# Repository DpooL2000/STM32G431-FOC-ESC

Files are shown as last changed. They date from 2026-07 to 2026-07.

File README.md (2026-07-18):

# Bare-Metal Sensorless FOC Kernel

This repository contains the hardware designs and bare-metal firmware kernels for a high-frequency sensorless FOC drive engine optimized for low-inductance UAV motors.

## System Architecture

*   **Microcontroller:** STM32G431 (170MHz Cortex-M4, utilizing internal CORDIC hardware co-processor).
*   **Target Dynamics:** 2300KV BLDC motor turning a 5-inch tri-blade propeller.
*   **Stator Identification Profile:**
    *   Phase Inductance (Ls): ~31 μH
    *   Phase Resistance (Rs): ~90 mΩ
    *   Flux Linkage (λ): ~0.00041 Wb
*   **Power Stage:** Discrete IR2101 gate drivers driving AOT418 MOSFETs, decoupled via high-speed 6N137 optocouplers for hardware shoot-through mitigation.
*   **Current Topology:** Injected low-side sensing through AD8418 current amplifiers paired with 2 mΩ shunts.

---

## Firmware Kernel Breakdown

### Core Execution Modules
*   **Pure Voltage Mode Engine:** Bypasses traditional high-lag PI current controllers to prevent phase delay at electrical frequencies exceeding 1500 Hz (30,000+ RPM).
*   **State-Space Flux Observer:** Zero-lag geometric flux estimation running at a rigid 24 kHz cycle using hardware CORDIC `get_Fast_Atan2()` calculations.
*   **Synchronous PWM Sampling:** Injected ADC conversions strictly aligned to center-count PWM timer events to read phase currents during low-side switching "quiet zones".

### The 5-Stage Spooling Sequence
1.  **OFF / CALIBRATE:** Measures operational amplifier baseline offsets.
2.  **ALIGN:** Asserts static vector to orient the rotor precisely at 0°.
3.  **OPEN_LOOP_RAMP:** Executes high-frequency blind step injection to break stator cogging torque.
4.  **FOC_BLEND:** Computes vector cross-fade from open-loop tracking to observer loop lock.
5.  **CLOSED_LOOP_FOC:** Complete handoff to pure sensorless geometric tracking.

---

## The High-RPM Non-Linear Boundary ("The Jerk")

A dedicated engineering post-mortem detailing why textbook industrial algorithms break down under microhenry, ultra-low mass environments:

*   **Cross-Coupling Destabilization:** At 40%–50% throttle, a microscopic 40 μs computational latency combined with intense reactive back-EMF cross-coupling (V = -ω * L * Iq) forces massive D-axis current (Id) spikes that derail the flux observer.
*   **Textbook Failures Documented:**
    *   **ADC Slew Limiting:** Clamping di/dt transitions starved the observer because a 31 μH coil at 12 V naturally generates an massive ~387,000 A/s rise rate.
    *   **Digital Flywheel PLLs:** Inertial filters introduced excessive mathematical phase lag, failing to track the sharp mechanical acceleration profiles of light drone props.

---

## Hardware Realities & Deadtime Distortion

*   **Pulse Devourment:** Insights on trying to execute an asymmetrical multirate loop (48 kHz PWM / 24 kHz FOC).
*   **The Math vs. Reality:** At 48 kHz, a 10% throttle command requires highly narrow 2.08 μs pulses. The gate driver's unavoidable physical deadtime (~0.5 μs) swallows a massive portion of the pulse width. This starves the stator coils of actual voltage relative to what the observer calculates, crashing the engine.
*   **Mitigation Strategy:** Reverted to a strictly synchronous 1:1 execution framework (24 kHz PWM / 24 kHz FOC) to preserve physical pulse widths.

---

## Live Telemetry Architecture

*   **The Binary Stream:** A raw, low-overhead 49-byte struct pushed at 1 kHz over a custom 2 Mbaud UART pipeline.
*   **UI Parser:** Custom PyQtGraph-driven GUI visualizing localized metrics (Id, Iq, Vd, Vq, and phase lag angle) in real-time.

---

## Repository Layout

*   **/hardware**: Layout files, optocoupler isolation circuits, and gate driver schematics.
*   **/firmware**: Clean bare-metal C modules, calibration tools, and parameter identification scripts.

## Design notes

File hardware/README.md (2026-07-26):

# Hardware Engineering & Power Stage Architecture

This directory contains the schematic and PCB layout for the bare-metal STM32G431 ESC, designed specifically for high-frequency sensorless FOC.

<p align="center">
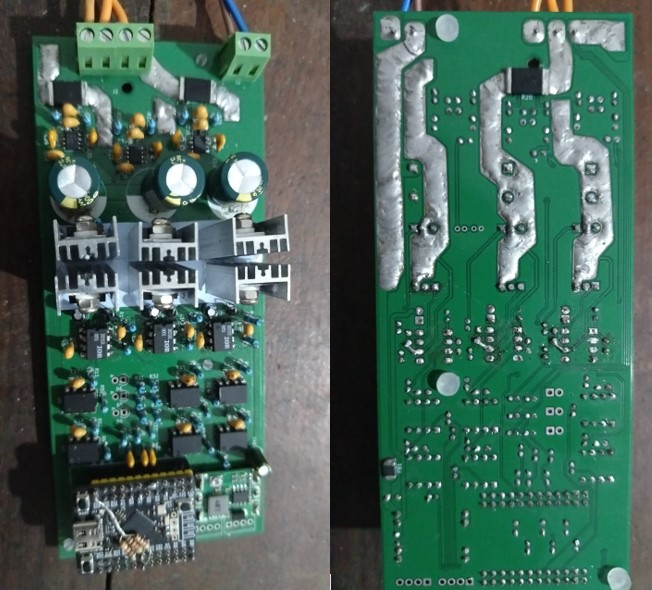
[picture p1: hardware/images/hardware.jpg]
Carrier Board Layout

</p>

## Power Stage & Isolation Topology
* **Gate Drivers:** Discrete IR2101 drivers pushing IRFZ44N MOSFETs.
* **Galvanic Isolation:** High-speed 6N137 optocouplers isolate the logic layer (STM32) from the power stage to prevent ground bounce and protect against high *di/dt* switching noise.
* **Power Management:** MP1584 Buck converter stepping the main 12V bus down to a stable 5V for logic and gate driver staging.

## Switching Dynamics & Thermal Constraints
The hardware was simulated and validated against exact MOSFET switching characteristics:
* **Miller Plateau Management:** Gate charge limits and switching losses were modeled at varying drive currents to optimize the transition through the Miller Plateau.
* **Shoot-Through Protection:** Hardware deadtime is physically characterized at 900 ns to ensure absolute safe-state switching during high/low side handoffs.

## Signal Conditioning & Analog Front End (AFE)
* **Current Sensing:** Low-side current measurement utilizing 2 mΩ shunts paired with AD8418 current sense amplifiers for precision synchronous sampling.
* **BEMF Sensing:** Phase voltages (A, B, C) are stepped down via precise resistor divider networks (10k/1k).
* **Hardware Filtering:** The BEMF signals pass through dedicated RC low-pass filters tuned to a 172.1 kHz cutoff frequency, resulting in a known, deterministic 7.9° phase lag that is compensated for in software.

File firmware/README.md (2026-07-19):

# Firmware Kernel & Control Systems

This directory contains the bare-metal C implementation of the sensorless FOC loop, executing on the STM32G431 Cortex-M4.

## Hardware Abstraction & Pin Mapping
The system is tightly coupled to the MCU hardware timers and ADCs for deterministic execution:

| Function | Signal | STM32 Pin | Peripheral / Channel |
| :--- | :--- | :--- | :--- |
| **Phase U PWM** | High / Low | PA8 / PB13 | TIM1_CH1 / TIM1_CH1N |
| **Phase V PWM** | High / Low | PA9 / PB14 | TIM1_CH2 / TIM1_CH2N |
| **Phase W PWM** | High / Low | PA10 / PB15 | TIM1_CH3 / TIM1_CH3N |
| **Phase U Current** | Injected | PB1 | ADC1_IN12 |
| **Phase V Current** | Injected | PA0 | ADC2_IN1 |
| **Phase W Current** | Injected | PA3 | ADC1_IN3 / ADC2_IN3 |
| **BEMF Sensing** | Phase U, V, W | PB0, PA1, PA7 | ADC Channels 15, 2, 3 |
| **Telemetry** | UART TX / RX | PB10 / PB11 | USART3 |

## Synchronous Execution & Timing
* **Center-Aligned PWM:** The kernel utilizes center-aligned (triangle) PWM generation rather than edge-aligned. 
* **Quiet-Zone ADC Sampling:** ADC conversions are strictly triggered at the center of the PWM cycle (the "quiet zone") to guarantee clean phase current samples free of switching noise.
* **Execution Overhead:** The core control loop executes in exactly 2728 clock cycles. At the current clock speed, total computation time is 16.05 μs, operating well within the maximum 50 μs budget of the 24kHz control loop.

## State Observer & Diagnostics
To tune the sensorless tracking, a custom high-speed telemetry pipeline pushes real-time data to a PyQtGraph visualizer:
* **Clarke Transform Validation:** Live tracking of $I_{\alpha}$ and $I_{\beta}$ currents against injected phase voltages ensures symmetrical waveform synthesis.
* **Flux Observer Synchronization:** Diagnostic tools allow real-time visualization of the origin drift and the estimated flux angle versus the open-loop command to ensure a seamless "FOC Blend" handoff.

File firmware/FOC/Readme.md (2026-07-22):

# Sensorless FOC Master Kernel

This directory contains the firmware evolution for a high-performance, sensorless Field Oriented Control (FOC) drive targeting the STM32G431. The control scheme utilizes a highly optimized 20kHz hard-sync loop, hardware CORDIC acceleration, and advanced observer models (Active Flux / SMO)

## Version History & Improvements

| Version / Era | Key Features & Architectural Improvements |
| :--- | :--- |
| **V2.x (Racer)** | • **Park-and-Spin State Machine:** Smooth transition from IDLE -> ALIGN -> RAMP -> CLOSED_LOOP.<br>• **SVPWM Modulator:** Space Vector PWM implementation for optimized voltage utilization.<br>• Continuous background BEMF observer tracking during open-loop spooling. |
| **V3.1 - V3.2** | • **ZOH SMO / Active Flux Observer:** Transitioned to stable ZOH state feedback matrix and Active Flux calculations.<br>• **Lambda Measurement:** Dedicated state machine for identifying motor flux linkage (V.s/rad) at 150 rad/s.<br>• CORDIC-accelerated Cross-Product PLL for speed/angle tracking. |
| **V3.4 - V4.2** | • **CORDIC Safety Fix:** Enforced `NARGS=1` constraints to prevent mathematical poisoning during sequential hardware reads.<br>• **Adaptive Feedforward:** Phase compensation mathematically subtracted to erase observer lead and lock onto the physical rotor.<br>• **Binary Telemetry:** High-speed, exactly packed 49-byte struct dumping at 1kHz for live data visualization. |
| **V5.1.x** | • **Flux Weakening:** Dynamic lambda attenuation (reducing by 2% per 100 rad/s) for ultra-high-speed operation (>500 rad/s).<br>• **Dynamic Gamma:** Adaptive observer stiffness to suppress high-frequency ADC noise at high RPMs.<br>• **Smooth Blending:** LERP-based `FOC_BLEND` state to seamlessly fade from open-loop voltage pushing to active throttle tracking. |
| **V5.2** | • **Digital Flywheel:** Alpha-Beta Tracking filter utilizing predictive momentum and position/speed stiffness gains.<br>• **Predictive Phase Advance:** Compensates for the ~40µs CPU/PWM hardware delay by aiming voltage where the rotor *will* be.<br>• **D-Axis Feedforward:** Dynamic cross-coupling cancellation (`-omega * L * Iq`) mapped directly into the Inverse Park Transform. |

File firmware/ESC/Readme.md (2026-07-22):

# Bare-Metal Six-Step ESC Kernel 

This directory contains the development progression of a custom, bare-metal six-step ESC for the WeAct STM32G431. The firmware evolves from a basic open/closed-loop commutator to an advanced, EMI-hardened drive with dynamic stall recovery and auto-advancing BEMF tracking.

## Version History & Improvements

| Version | Key Features & Architectural Improvements |
| :--- | :--- |
| **V1.1** | • Initial bare-metal 6-step commutator using TIM1 center-aligned PWM.<br>• Injected BEMF scanning via ADC1.<br>• ELRS CRSF protocol parsing and BLDC audio engine. |
| **V1.2** | • **Stall Protection:** Introduced a 5ms closed-loop watchdog timeout.<br>• **Recovery:** Forces a 500ms coasting period upon sync loss before allowing a restart. |
| **V1.3** | • **Soft Start:** Implemented a slew rate limiter (15V/s ramp) for smooth spooling.<br>• **V/f Override:** Calculates safe spool voltage dynamically based on step delay. |
| **V1.4** | • **Dynamic Watchdog:** Timeout adapts to motor speed (4x predicted step duration).<br>• **High-Accel Slew Rate:** Increased voltage ramp to 120 V/s for agile throttle response.<br>• **Mandatory Cooldown:** Extended the stall recovery window to a strict 2 seconds. |
| **V1.5** | • **Auto-Advance Anti-Stall:** Forces a commutation step on timeout to keep momentum alive during false positives.<br>• **Strike System:** Implemented a 4-strike error counter before declaring a true physical prop jam. |
| **V1.6** | • **EMI Bulletproofing:** Hardware UART error clearing (ORE/NE/FE/PE) to prevent stall spikes from freezing telemetry.<br>• **ADC Valley Protection:** Clamped max duty cycle to 95% to guarantee a 5% window for clean BEMF sampling.<br>• **Radio Failsafe:** Instantly kills throttle if ELRS packets are delayed by >200ms.<br>• **Phantom Strike Fix:** Increased tolerance to 6 strikes and prevents phantom errors during open-loop. |

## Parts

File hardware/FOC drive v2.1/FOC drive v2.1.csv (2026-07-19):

Reference | Qty | Value | DNP | Exclude from BOM | Exclude from Board | Footprint | Datasheet
C1,C2,C3 | 3 | 1uF |  |  |  |  | ~
C4,C5,C6,C13,C14,C15,C16,C17,C18 | 9 | 0.1uF |  |  |  |  | ~
C7,C8,C9 | 3 | 10uF |  |  |  |  | ~
C10,C11,C12 | 3 | 1000uF |  |  |  |  | ~
C19,C20,C21 | 3 | 10nF |  |  |  |  | ~
C22,C23,C24,C25,C26,C27,C28,C29,C30,C31,C32,C33 | 12 | 1nF |  |  |  |  | ~
D1,D2,D3 | 3 | 1N5819 |  |  |  | Diode_THT:D_DO-41_SOD81_P10.16mm_Horizontal | http://www.vishay.com/docs/88525/1n5817.pdf
D4,D5,D6 | 3 | 3.3V |  |  |  |  | ~
J1 | 1 | Screw_Terminal_01x02 |  |  |  |  | ~
J2 | 1 | Screw_Terminal_01x03 |  |  |  |  | ~
J3 | 1 | Screw_Terminal_01x04 |  |  |  |  | ~
MP1584 | 1 | ~
Q1 | 1 | IRFZ44N |  |  |  | irfz44n:TO254P1016X419X2286-3
Q2,Q3,Q4,Q5,Q6 | 5 | IRFZ44N |  |  |  | IRFZ44N:TO254P1016X419X2286-3
R1,R2,R3,R4,R5,R6 | 6 | 330 |  |  |  |  | ~
R7,R8,R9,R10,R11,R12,R31,R33,R35 | 9 | 1k |  |  |  |  | ~
R13,R14,R15,R16,R17,R18 | 6 | 22 |  |  |  |  | ~
R19,R20,R21 | 3 | R002 |  |  |  |  | ~
R22,R23,R24,R37,R38,R39 | 6 | 100 |  |  |  |  | ~
R25,R26,R27,R28,R29,R30 | 6 | 10 |  |  |  |  | ~
R32,R34,R36,R40,TH1 | 5 | 10k |  |  |  |  | ~
STM32G1 | 1 | ~ |  |  |  | STM32-sheilds:STM32_G431
U1,U2,U3 | 3 | AD8418 |  |  |  | Package_SO:SOIC-8_3.9x4.9mm_P1.27mm | https://www.analog.com/media/en/technical-documentation/data-sheets/AD8418.pdf
U4,U5,U6,U7,U10,U11 | 6 | 6N137 |  |  |  | Package_DIP:DIP-8_W7.62mm | https://docs.broadcom.com/docs/AV02-0940EN
U8 | 1 | IR2101 |  |  |  | Package_DIP:DIP-8_W7.62mm_Socket_LongPads | https://www.infineon.com/dgdl/ir2101.pdf?fileId=5546d462533600a4015355c7a755166c
U9,U12 | 2 | IR2101 |  |  |  |  | https://www.infineon.com/dgdl/ir2101.pdf?fileId=5546d462533600a4015355c7a755166c

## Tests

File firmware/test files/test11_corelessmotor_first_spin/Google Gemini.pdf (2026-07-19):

## STM32G431 Motor Controller: Master Technical Handover

Project Phase: Diagnostic / Sensorless ESC Transition Engineer: CK

### 1. Physical Layer & Component Engineering

Isolation & Gate Drive Logic

Gate Drive Strategy: Driving the IR2104 by connecting IN and SD pins together to a

single PWM signal.

Benefit: Eliminates separate dead-time logic from the MCU; the IR2104 provides its

own internal dead-time (~520ns).

Optocouplers (4 Total):

3x 6N137: High-speed digital optos for Phase signals. Note: These are inverting.

STM32 LOW = Opto LED ON = Opto Output LOW = IR2104 IN/SD HIGH.

1x PC817: Global Shutdown/Enable path (Active High).

Gate Drivers: 3x IR2104.

The XNOR Discovery: During test8 , we found previous chip batches acted like XNOR

gates (requiring specific signal mismatches to enable). We are transitioning to new

hardware to restore standard behavior.

Bootstrap Circuit: Standard diode + capacitor per phase. Requires periodic low-side

switching (LO ON) to maintain high-side gate charge.

Signal Conditioning & Filtering

RC Filters: 15.6kHz Low-Pass filter on every internal OPAMP non-inverting input (PB0, PA1,

PA7).

Voltage Clamping: Schottky diodes connected to 3.3V rails on each OPAMP input pin to

protect the STM32 from high-voltage back-EMF spikes.

Decoupling: 0.1uF and 1uF ceramic capacitors distributed across all IC supply pins (MCU,

Drivers, OPAMPs).

Snubbers: RC snubbers placed across MOSFET Drain-Source to suppress high-frequency

switching ringing.

### 2. Verified Code Snippets (The "Hard-Learned" Blocks)

Working CORDIC Interface (Fixed)

Crucial bit-masking for the NRES (2 results) and PRECISION (6 iterations) flags.

inline void get_Fast_Sin_Cos(float angle_rad, float* out_sin, float* out_cos) {

while(angle_rad > PI) angle_rad -= 2.0f * PI;

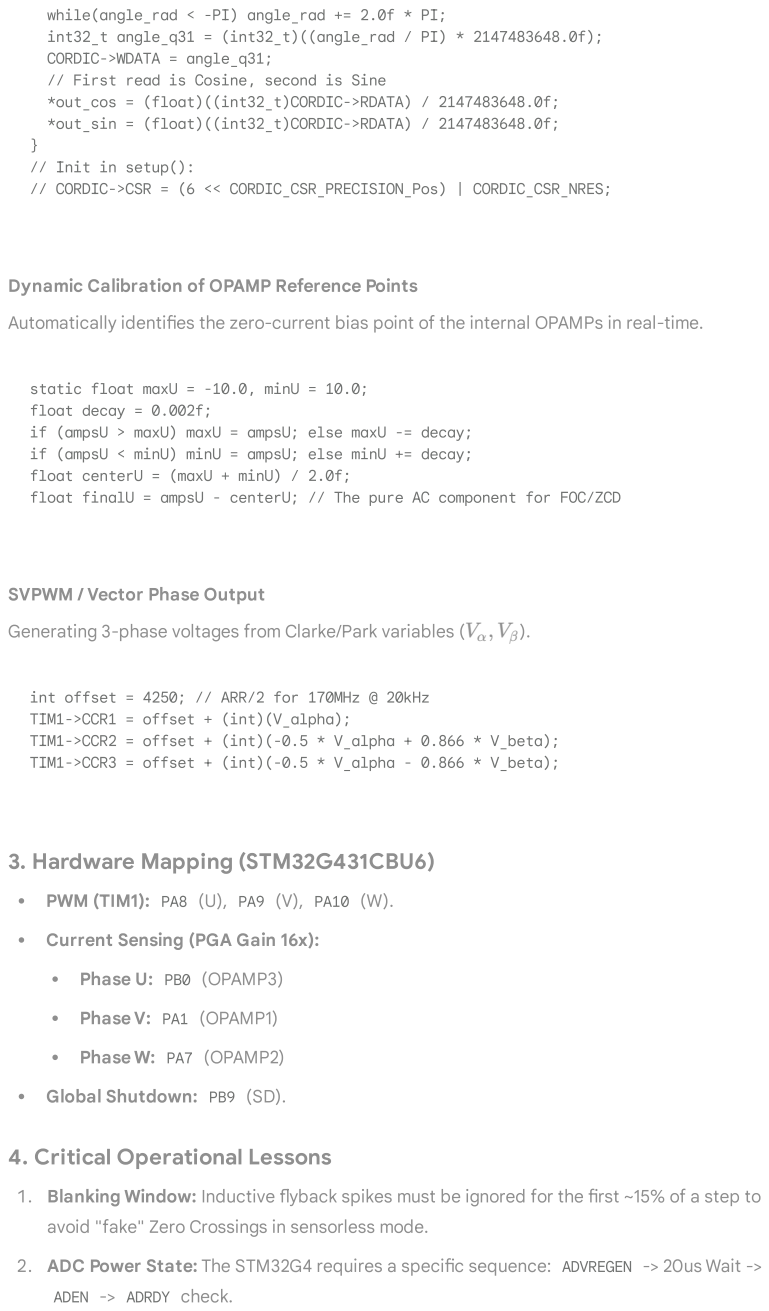
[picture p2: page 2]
int32_t angle_q31 = (int32_t)((angle_rad / PI) * 2147483648.0f);; CORDIC->WDATA = angle_q31;; // CORDIC->CSR = (6 << CORDIC_CSR_PRECISION_Pos) | CORDIC_CSR_NRES;; float decay = 0.002f;; Generating 3-phase voltages from Clarke/Park variables (; TIM1->CCR1 = offset + (int)(V_alpha);; TIM1->CCR2 = offset + (int)(-0.5 * V_alpha + 0.866 * V_beta);; TIM1->CCR3 = offset + (int)(-0.5 * V_alpha - 0.866 * V_beta);; 3. Hardware Mapping (STM32G431CBU6); PWM (TIM1): PA8 (U), PA9 (V), PA10 (W).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

while(angle_rad < -PI) angle_rad += 2.0f * PI;

// First read is Cosine, second is Sine

*out_cos = (float)((int32_t)CORDIC->RDATA) / 2147483648.0f;

*out_sin = (float)((int32_t)CORDIC->RDATA) / 2147483648.0f;

// Init in setup():

Dynamic Calibration of OPAMP Reference Points

Automatically identifies the zero-current bias point of the internal OPAMPs in real-time.

static float maxU = -10.0, minU = 10.0;

if (ampsU > maxU) maxU = ampsU; else maxU -= decay;

if (ampsU < minU) minU = ampsU; else minU += decay;

float centerU = (maxU + minU) / 2.0f;

float finalU = ampsU - centerU; // The pure AC component for FOC/ZCD

SVPWM / Vector Phase Output

int offset = 4250; // ARR/2 for 170MHz @ 20kHz

Current Sensing (PGA Gain 16x):

Global Shutdown: PB9 (SD).

4. Critical Operational Lessons

1. Blanking Window: Inductive flyback spikes must be ignored for the first ~15% of a step to

avoid "fake" Zero Crossings in sensorless mode.

2. ADC Power State: The STM32G4 requires a specific sequence: ADVREGEN -> 20us Wait ->

ADEN -> ADRDY check.

3. V/f Relationship: PWM duty must scale linearly with frequency to maintain torque against

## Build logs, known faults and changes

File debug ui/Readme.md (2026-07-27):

# Testing currents



# Flux tracking




# Motor parameter mismatches




# Aligning



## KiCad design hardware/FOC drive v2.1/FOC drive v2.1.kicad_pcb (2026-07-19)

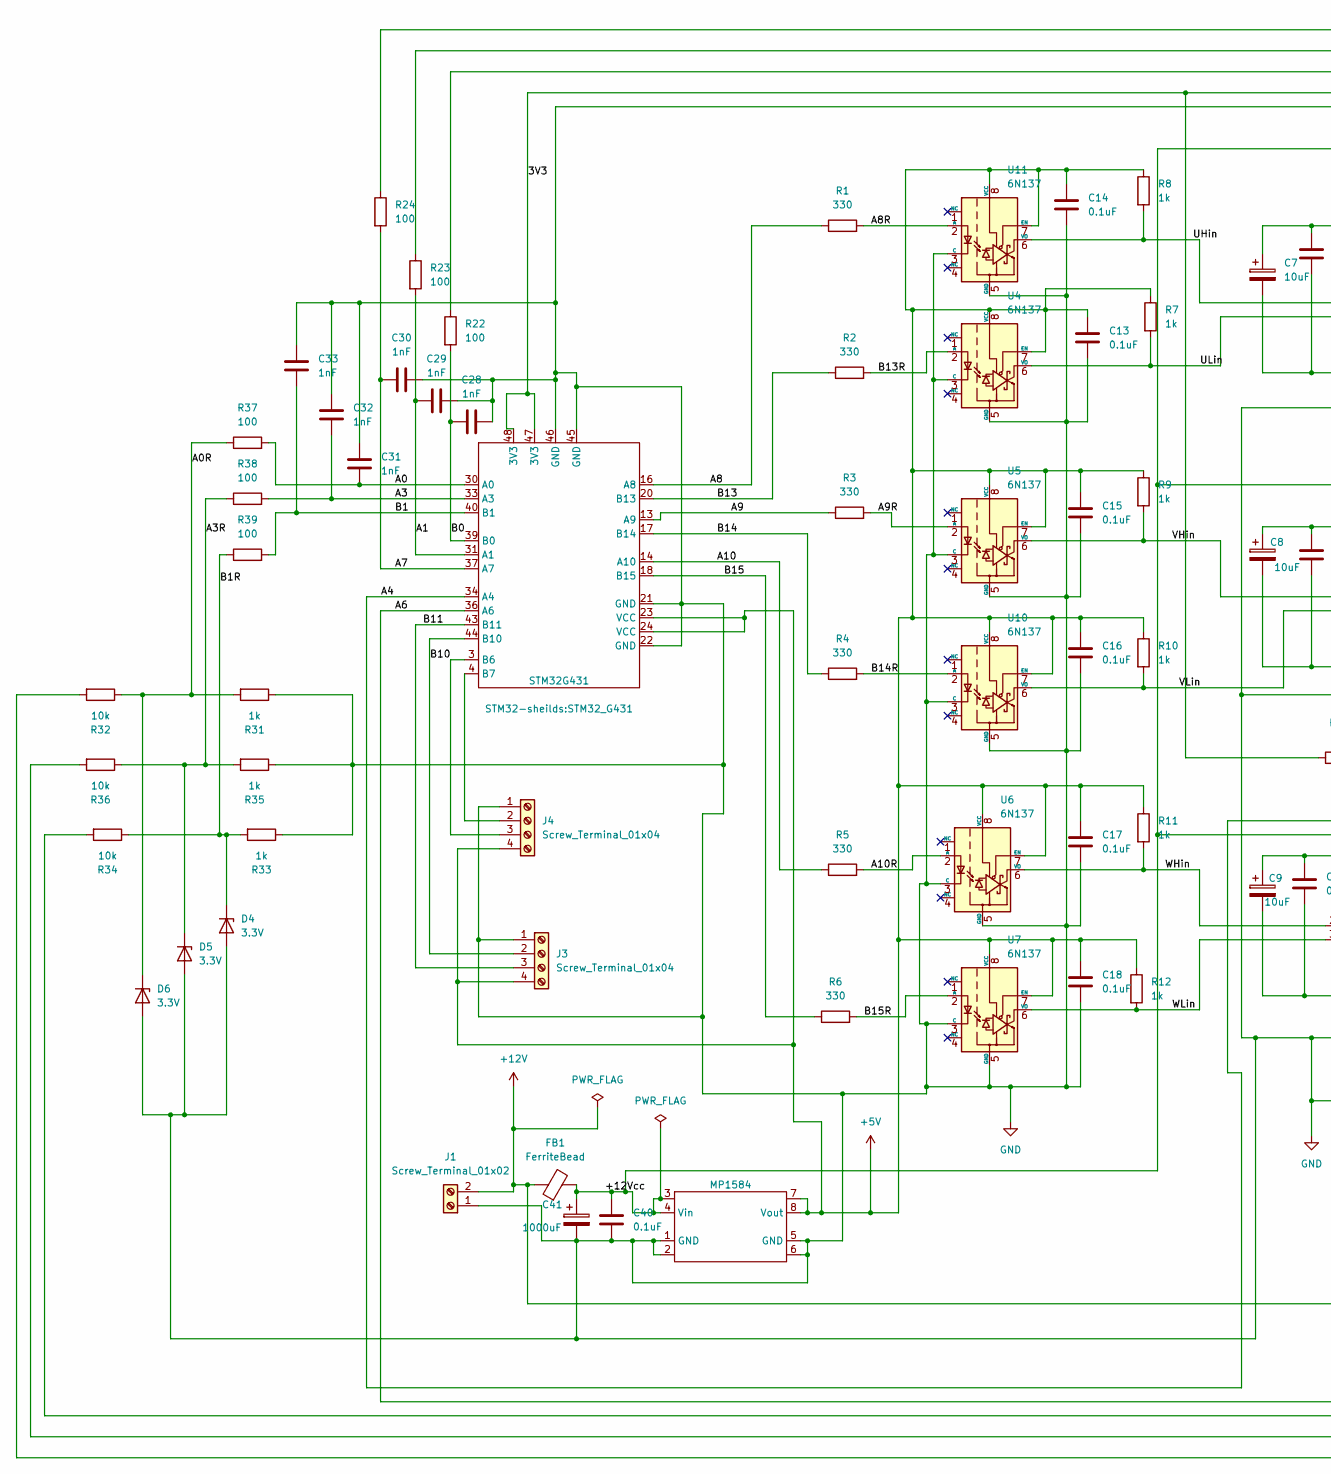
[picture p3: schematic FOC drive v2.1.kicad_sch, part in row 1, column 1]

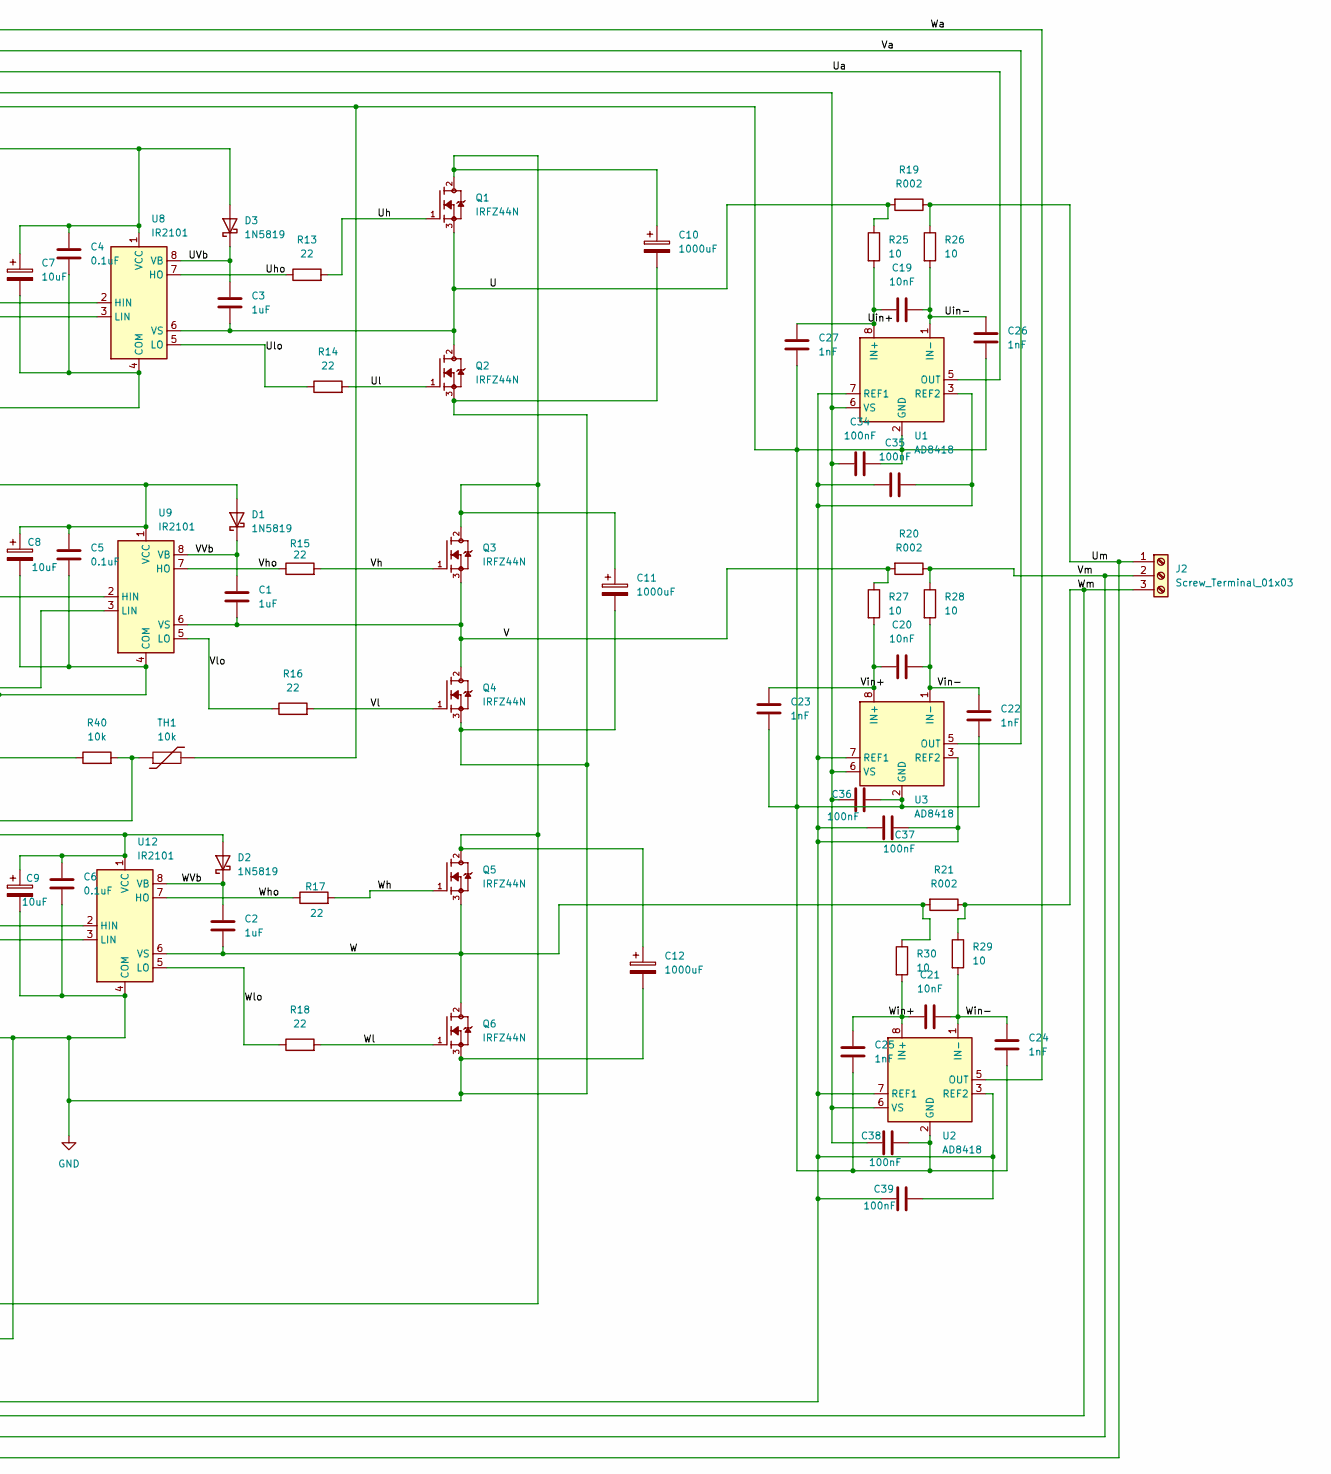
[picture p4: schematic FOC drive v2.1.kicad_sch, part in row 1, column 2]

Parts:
C1, C2, C3: 1uF; C_Disc_D3.0mm_W2.0mm_P2.50mm
C4, C5, C6, C13, C14, C15, C16, C17, C18, C40: 0.1uF; C_Disc_D3.0mm_W2.0mm_P2.50mm
C7, C8, C9: 10uF; C_Radial_D5.0mm_H5.0mm_P2.00mm
C10, C11, C12: 1000uF; CP_Radial_D16.0mm_P7.50mm
C19, C20, C21: 10nF; C_Disc_D3.0mm_W2.0mm_P2.50mm
C22, C23, C24, C25, C26, C27, C28, C29, C30, C31, C32, C33: 1nF; C_Disc_D3.0mm_W2.0mm_P2.50mm
C34, C35, C36, C37, C38, C39: 100nF; C_Disc_D3.0mm_W2.0mm_P2.50mm
C41: 1000uF; CP_Radial_D5.0mm_P2.50mm
D1, D2, D3: 1N5819; D_DO-41_SOD81_P2.54mm_Vertical_AnodeUp
D4, D5, D6: 3.3V; D_DO-41_SOD81_P2.54mm_Vertical_AnodeUp
FB1: FerriteBead; L_1812_4532Metric
J1: Screw_Terminal_01x02; TerminalBlock_Phoenix_PT-1,5-2-5.0-H_1x02_P5.00mm_Horizontal
J2: Screw_Terminal_01x03; TerminalBlock_Phoenix_PT-1,5-3-5.0-H_1x03_P5.00mm_Horizontal
J3, J4: Screw_Terminal_01x04; TerminalBlock_Phoenix_MPT-0,5-4-2.54_1x04_P2.54mm_Horizontal
MP1584: MP1584
Q1, Q2, Q3, Q4, Q5, Q6: IRFZ44N; TO-220-3_Vertical; PARTREV 09/21/10
R1, R2, R3, R4, R5, R6: 330; R_Axial_DIN0204_L3.6mm_D1.6mm_P1.90mm_Vertical
R7, R8, R9, R10, R11, R12, R31, R33, R35: 1k; R_Axial_DIN0204_L3.6mm_D1.6mm_P1.90mm_Vertical
R13, R14, R15, R16, R17, R18: 22; R_Axial_DIN0204_L3.6mm_D1.6mm_P1.90mm_Vertical
R19, R20, R21: R002; R_4020_10251Metric
R22, R23, R24, R37, R38, R39: 100; R_Axial_DIN0204_L3.6mm_D1.6mm_P1.90mm_Vertical
R25, R26, R27, R28, R29, R30: 10; R_Axial_DIN0204_L3.6mm_D1.6mm_P1.90mm_Vertical
R32, R34, R36, R40: 10k; R_Axial_DIN0204_L3.6mm_D1.6mm_P1.90mm_Vertical
STM32G431: STM32_G431
TH1: 10k; R_Axial_DIN0204_L3.6mm_D1.6mm_P1.90mm_Vertical
U1, U2, U3: AD8418; SOIC-8_3.9x4.9mm_P1.27mm
U4, U5, U6, U7, U10, U11: 6N137; DIP-8_W7.62mm
U8, U9, U12: IR2101; DIP-8_W7.62mm_LongPads

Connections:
+5V: C13.1, C14.1, C15.1, C16.1, C17.1, C18.1, J3.4, J4.4, MP1584.7, MP1584.8 (Vout), R7.1, R8.1, R9.1, R10.1, R11.1, R12.1, STM32G431.23 (VCC), STM32G431.24 (VCC), U4.7 (EN), U4.8 (VCC), U5.7 (EN), U5.8 (VCC), U6.7 (EN), U6.8 (VCC), U7.7 (EN), U7.8 (VCC), U10.7 (EN), U10.8 (VCC), U11.7 (EN), U11.8 (VCC)
+12V: C10.1, C11.1, C12.1, FB1.1, J1.2, Q1.2, Q3.2, Q5.2
/3V3: C34.2, C36.2, C38.2, R40.1, STM32G431.47 (3V3), STM32G431.48 (3V3), U1.6 (VS), U2.6 (VS), U3.6 (VS)
/+12Vcc: C4.1, C5.1, C6.1, C7.1, C8.1, C9.1, C40.1, C41.1, D1.2 (A), D2.2 (A), D3.2 (A), FB1.2, MP1584.3, MP1584.4 (Vin), U8.1 (VCC), U9.1 (VCC), U12.1 (VCC)
/A0: C31.1, R37.2, STM32G431.30 (A0)
/A0R: D6.1 (K), R31.2, R32.1, R37.1
/A1: C29.1, R23.2, STM32G431.31 (A1)
/A3: C32.1, R38.2, STM32G431.33 (A3)
/A3R: D5.1 (K), R35.2, R36.1, R38.1
/A4: R40.2, STM32G431.34 (A4), TH1.1
/A6: C35.1, C35.2, C37.1, C37.2, C39.1, C39.2, STM32G431.36 (A6), U1.3 (REF2), U1.7 (REF1), U2.3 (REF2), U2.7 (REF1), U3.3 (REF2), U3.7 (REF1)
/A7: C30.1, R24.2, STM32G431.37 (A7)
/A8: R1.1, STM32G431.16 (A8)
/A8R: R1.2, U11.2 (A)
/A9: R3.1, STM32G431.13 (A9)
/A9R: R3.2, U5.2 (A)
/A10: R5.1, STM32G431.14 (A10)
/A10R: R5.2, U6.2 (A)
/B0: C28.1, R22.2, STM32G431.39 (B0)
/B1: C33.1, R39.2, STM32G431.40 (B1)
/B1R: D4.1 (K), R33.2, R34.1, R39.1
/B10: J3.2, STM32G431.44 (B10)
/B11: J3.3, STM32G431.43 (B11)
/B13: R2.1, STM32G431.20 (B13)
/B13R: R2.2, U4.2 (A)
/B14: R4.1, STM32G431.17 (B14)
/B14R: R4.2, U10.2 (A)
/B15: R6.1, STM32G431.18 (B15)
/B15R: R6.2, U7.2 (A)
/U: C3.2, Q1.3, Q2.2, R19.2, R25.1, U8.6 (VS)
/UHin: R8.2, U8.2 (HIN), U11.6 (VO)
/ULin: R7.2, U4.6 (VO), U8.3 (LIN)
/UVb: C3.1, D3.1 (K), U8.8 (VB)
/Ua: R22.1, U1.5 (OUT)
/Uh: Q1.1, R13.2
/Uho: R13.1, U8.7 (HO)
/Uin+: C19.2, C27.1, R25.2, U1.8 (IN+)
/Uin-: C19.1, C26.1, R26.2, U1.1 (IN-)
/Ul: Q2.1, R14.2
/Ulo: R14.1, U8.5 (LO)
/Um: J2.1, R19.1, R26.1, R32.2
/V: C1.2, Q3.3, Q4.2, R20.2, R27.1, U9.6 (VS)
/VHin: R9.2, U5.6 (VO), U9.2 (HIN)
/VLin: R10.2, U9.3 (LIN), U10.6 (VO)
/VVb: C1.1, D1.1 (K), U9.8 (VB)
/Va: R23.1, U3.5 (OUT)
/Vh: Q3.1, R15.2
/Vho: R15.1, U9.7 (HO)
/Vin+: C20.2, C23.1, R27.2, U3.8 (IN+)
/Vin-: C20.1, C22.1, R28.2, U3.1 (IN-)
/Vl: Q4.1, R16.2
/Vlo: R16.1, U9.5 (LO)
/Vm: J2.2, R20.1, R28.1, R36.2
/W: C2.2, Q5.3, Q6.2, R21.2, R30.1, U12.6 (VS)
/WHin: R11.2, U6.6 (VO), U12.2 (HIN)
/WLin: R12.2, U7.6 (VO), U12.3 (LIN)
/WVb: C2.1, D2.1 (K), U12.8 (VB)
/Wa: R24.1, U2.5 (OUT)
/Wh: Q5.1, R17.2
/Who: R17.1, U12.7 (HO)
/Win+: C21.2, C25.1, R30.2, U2.8 (IN+)
/Win-: C21.1, C24.1, R29.2, U2.1 (IN-)
/Wl: Q6.1, R18.2
/Wlo: R18.1, U12.5 (LO)
/Wm: J2.3, R21.1, R29.1, R34.2
GND: C4.2, C5.2, C6.2, C7.2, C8.2, C9.2, C10.2, C11.2, C12.2, C13.2, C14.2, C15.2, C16.2, C17.2, C18.2, C22.2, C23.2, C24.2, C25.2, C26.2, C27.2, C28.2, C29.2, C30.2, C31.2, C32.2, C33.2, C34.1, C36.1, C38.1, C40.2, C41.2, D4.2 (A), D5.2 (A), D6.2 (A), J1.1, J3.1, J4.1, MP1584.1 (GND), MP1584.2, MP1584.5 (GND), MP1584.6, Q2.3, Q4.3, Q6.3, R31.1, R33.1, R35.1, STM32G431.21 (GND), STM32G431.22 (GND), STM32G431.45 (GND), STM32G431.46 (GND), TH1.2, U1.2 (GND), U2.2 (GND), U3.2 (GND), U4.3 (C), U4.5 (GND), U5.3 (C), U5.5 (GND), U6.3 (C), U6.5 (GND), U7.3 (C), U7.5 (GND), U8.4 (COM), U9.4 (COM), U10.3 (C), U10.5 (GND), U11.3 (C), U11.5 (GND), U12.4 (COM)
unnamed: J4.2, STM32G431.4 (B7)
unnamed: J4.3, STM32G431.3 (B6)

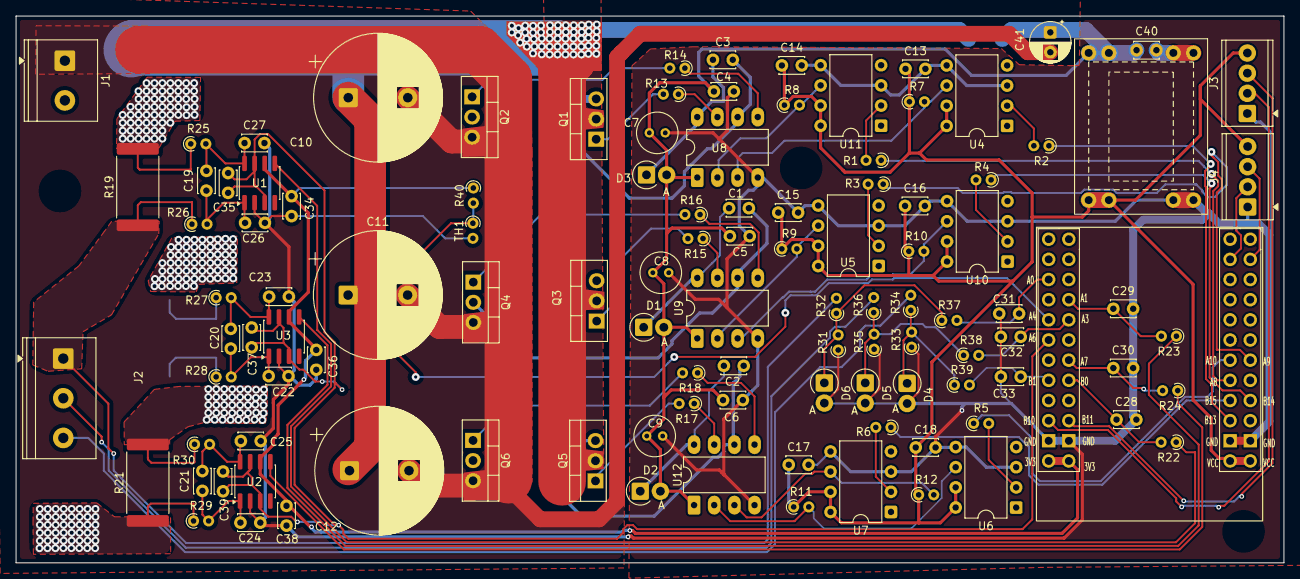
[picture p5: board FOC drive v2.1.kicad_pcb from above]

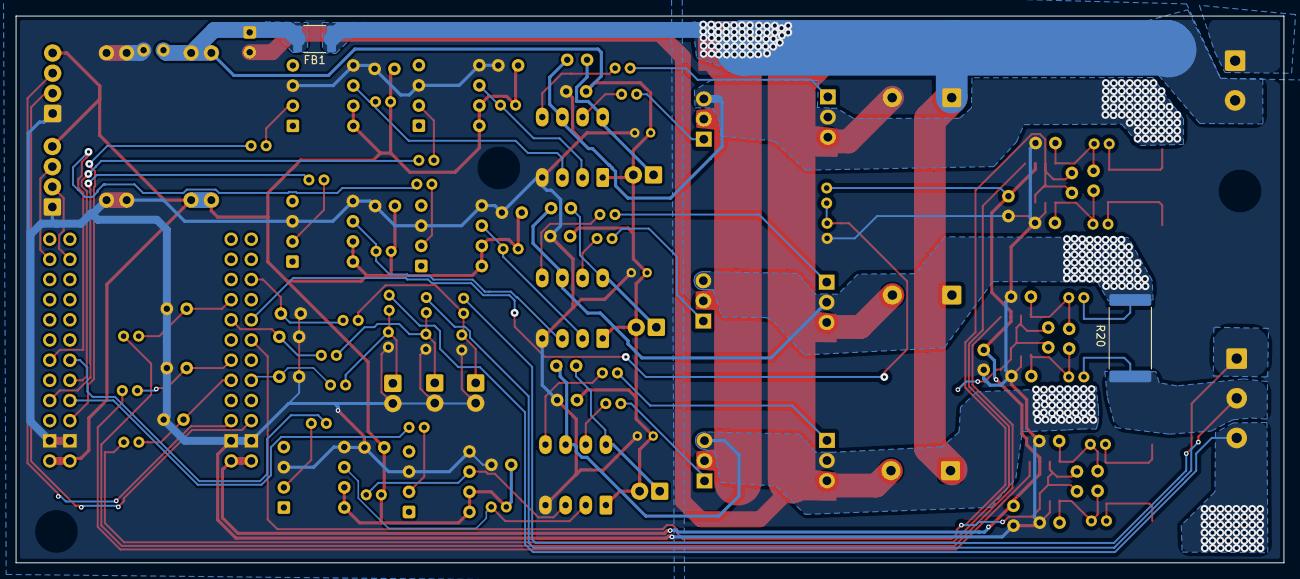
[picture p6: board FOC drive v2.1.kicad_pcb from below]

Board: 2 copper layers, 159.7 x 68.9 mm, 113 parts (2 on the bottom side), 68 nets.

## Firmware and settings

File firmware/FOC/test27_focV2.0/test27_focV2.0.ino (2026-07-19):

// =================================================================
// BARE-METAL SENSORLESS FOC - WEACT STM32G431 (V2.2 RACER KERNEL)
// Park-and-Spin State Machine | Observer Fix | CORDIC | SVPWM
// =================================================================
#include <Arduino.h>
#include <math.h>

#define _PI  3.14159265359f
#define _2PI 6.28318530718f
#define DRIVER_OFF HIGH

HardwareSerial ELRS_Serial(PB7, PB6); 
const int THROTTLE_CH = 2; // Channel 3 (AETR)

// --- MOTOR & SYSTEM CONFIG ---
const float POWER_SUPPLY = 12.0f;
const float R_phase      = 0.045f;
const float L_phase      = 0.000015f;

// --- STATE VARIABLES ---
float elrs_throttle      = 0.0f; 
bool  is_armed           = false;

float electrical_angle   = 0.0f;
float current_velocity   = 0.0f;
float obs_angle          = 0.0f;
float E_alpha            = 0.0f;
float E_beta             = 0.0f;
float last_pure_angle    = 0.0f;

// --- STARTUP STATE MACHINE ---
enum FOCState { IDLE, ALIGN, RAMP, CLOSED_LOOP };
FOCState motor_state = IDLE;
uint32_t state_timer = 0;

// To feed the observer accurate data
float V_alpha_cmd = 0.0f;
float V_beta_cmd  = 0.0f;

// --- ADC OFFSETS ---
int offset_U = 2048;
int offset_V = 2048;
int offset_W = 2048;

// ==========================================
// 1. HARDWARE CORDIC INTERFACE
// ==========================================
inline void get_Fast_Sin_Cos(float angle_rad, float* out_sin, float* out_cos) {
  while(angle_rad > _PI) angle_rad -= 2.0f * _PI;
  while(angle_rad < -_PI) angle_rad += 2.0f * _PI;
  int32_t angle_q31 = (int32_t)((angle_rad / _PI) * 2147483648.0f);
  CORDIC->WDATA = angle_q31;
  *out_cos = (float)((int32_t)CORDIC->RDATA) / 2147483648.0f;
  *out_sin = (float)((int32_t)CORDIC->RDATA) / 2147483648.0f;
}

// ==========================================
// 2. HARDWARE LOCKDOWN
// ==========================================
void hardware_lockdown() {
  pinMode(PA8,  OUTPUT); pinMode(PA9,  OUTPUT); pinMode(PA10, OUTPUT);
  pinMode(PB13, OUTPUT); pinMode(PB14, OUTPUT); pinMode(PB15, OUTPUT);
  digitalWrite(PA8,  DRIVER_OFF); digitalWrite(PB13, DRIVER_OFF);
  digitalWrite(PA9,  DRIVER_OFF); digitalWrite(PB14, DRIVER_OFF);
  digitalWrite(PA10, DRIVER_OFF); digitalWrite(PB15, DRIVER_OFF);
}

// ==========================================
// 3. ADVANCED TIMER 1 (INVERTER PWM & TRGO)
// ==========================================
void configureTIM1() {
  RCC->APB2ENR |= RCC_APB2ENR_TIM1EN;
  GPIOA->MODER  = (GPIOA->MODER  & ~0x3F0000)   | 0x2A0000;
  GPIOA->AFR[1] = (GPIOA->AFR[1] & ~0xFFF)      | 0x666;
  GPIOB->MODER  = (GPIOB->MODER  & ~0xFC000000) | 0xA8000000;
  GPIOB->AFR[1] = (GPIOB->AFR[1] & ~0xFFF00000) | 0x46600000;

  TIM1->CR1   = 0x20; TIM1->PSC = 0; TIM1->ARR = 4250;
  TIM1->CCMR1 = 0x6868; TIM1->CCMR2 = 0x68;
  TIM1->CCER  = 0xFFF; 
  TIM1->BDTR  = 0x80A0; 
  TIM1->CR2   = 0xF3F; TIM1->CR2 &= ~TIM_CR2_MMS_Msk; TIM1->CR2 |= (0x2 << TIM_CR2_MMS_Pos); 
  TIM1->EGR  |= 1; TIM1->CR1 |= 1;
}

// ==========================================
// 4. BARE-METAL ADCs (3-SHUNT INJECTED SCAN)
// ==========================================
void setup_bare_metal_ADCs() {
  RCC->AHB2ENR |= RCC_AHB2ENR_GPIOAEN | RCC_AHB2ENR_GPIOBEN | RCC_AHB2ENR_DAC1EN | RCC_AHB2ENR_ADC12EN;
  GPIOA->MODER |= (3 << 2) | (3 << 8) | (3 << 12) | (3 << 14); GPIOB->MODER |= (3 << 0);
  DAC1->CR |= 1; DAC1->DHR12R1 = 2048;
  ADC12_COMMON->CCR &= ~(3 << 16); ADC12_COMMON->CCR |= (1 << 16);
  ADC1->CR &= ~ADC_CR_DEEPPWD; ADC2->CR &= ~ADC_CR_DEEPPWD; delay(1);
  ADC1->CR |= ADC_CR_ADVREGEN; ADC2->CR |= ADC_CR_ADVREGEN; delay(1);
  ADC1->CR &= ~ADC_CR_ADCALDIF; ADC1->CR |= ADC_CR_ADCAL; while(ADC1->CR & ADC_CR_ADCAL);
  ADC2->CR &= ~ADC_CR_ADCALDIF; ADC2->CR |= ADC_CR_ADCAL; while(ADC2->CR & ADC_CR_ADCAL); delay(1);
  ADC1->ISR |= ADC_ISR_ADRDY; ADC1->CR |= ADC_CR_ADEN; while(!(ADC1->ISR & ADC_ISR_ADRDY));
  ADC2->ISR |= ADC_ISR_ADRDY; ADC2->CR |= ADC_CR_ADEN; while(!(ADC2->ISR & ADC_ISR_ADRDY));
  ADC1->SMPR1 |= (3 << 6); ADC1->SMPR2 |= (3 << 15); ADC2->SMPR1 |= (3 << 12); 
  ADC1->JSQR = (1 << 0) | (1 << 7) | (15 << 9) | (2 << 15);
  ADC2->JSQR = (0 << 0) | (1 << 7) | (4 << 9);
  ADC1->CR |= ADC_CR_JADSTART; ADC2->CR |= ADC_CR_JADSTART;
}

// ==========================================
// 5. BLDC AUDIO TONE ENGINE
// ==========================================
void playTone(int freq_hz, int duration_ms) {
  uint32_t period_us = 1000000 / freq_hz;
  uint32_t half_period = period_us / 2;
  uint32_t start_time = millis();
  uint32_t base_ccer = 0xFFF;
  while (millis() - start_time < duration_ms) {
    TIM1->CCR1 = (uint16_t)(0.12f * 4250.0f); TIM1->CCR2 = 0; TIM1->CCR3 = 0;
    TIM1->CCER = base_ccer; delayMicroseconds(half_period);
    TIM1->CCER = 0xAAA; delayMicroseconds(half_period);
  }
  TIM1->CCER = 0xAAA; 
}

// ==========================================
// 6. ELRS CRSF PROTOCOL PARSER
// ==========================================
void readELRS() {
  static uint8_t crsf_buf[64]; static uint8_t crsf_idx = 0; static uint32_t last_packet_ms = 0;
  if (USART1->ISR & (USART_ISR_ORE | USART_ISR_NE | USART_ISR_FE | USART_ISR_PE)) {
      USART1->ICR = USART_ICR_ORECF | USART_ICR_NECF | USART_ICR_FECF | USART_ICR_PECF;
  }
  while (ELRS_Serial.available()) {
    uint8_t b = ELRS_Serial.read();
    if (crsf_idx == 0 && b != 0xC8) continue; 
    crsf_buf[crsf_idx++] = b;
    if (crsf_idx >= 2 && crsf_idx >= crsf_buf[1] + 2) { 
        if (crsf_buf[2] == 0x16) { 
          last_packet_ms = millis(); 
          uint16_t ch[4];
          ch[0] = (crsf_buf[3] | crsf_buf[4] << 8) & 0x07FF;
          ch[1] = (crsf_buf[4] >> 3 | crsf_buf[5] << 5) & 0x07FF;
          ch[2] = (crsf_buf[5] >> 6 | crsf_buf[6] << 2 | crsf_buf[7] << 10) & 0x07FF;
          float raw_thr = (ch[THROTTLE_CH] - 172) / (1811.0f - 172.0f);
          elrs_throttle = constrain(raw_thr, 0.0f, 1.0f);
          if (elrs_throttle < 0.05f) elrs_throttle = 0.0f;
          
          if (!is_armed && elrs_throttle == 0.0f) {
             is_armed = true;
             Serial.println("ARMING DETECTED! Playing Doo-Wop...");
             playTone(880, 250); delay(50); playTone(1175, 400); 
          }
        }
        crsf_idx = 0; 
    }
    if (crsf_idx >= 64) crsf_idx = 0; 
  }
  if (millis() - last_packet_ms > 200) elrs_throttle = 0.0f; // Failsafe
}

// ==========================================
// 7. SETUP
// ==========================================
void setup() {
  hardware_lockdown(); Serial.begin(115200); delay(2000);
  Serial.println("--- BARE-METAL FOC V2.2 (STATE MACHINE) ---");
  CoreDebug->DEMCR |= CoreDebug_DEMCR_TRCENA_Msk; DWT->CYCCNT = 0; DWT->CTRL |= DWT_CTRL_CYCCNTENA_Msk;

  RCC->AHB1ENR |= RCC_AHB1ENR_CORDICEN;
  CORDIC->CSR = (6 << 4) | (1 << 18); // Precision 6, 2 Results
  
  setup_bare_metal_ADCs(); configureTIM1();  
  ELRS_Serial.setRx(PB7); ELRS_Serial.setTx(PB6); ELRS_Serial.begin(420000);

  playTone(1175, 150); playTone(1319, 150); playTone(1397, 150); delay(400);
  int cell_count = (int)(POWER_SUPPLY / 3.7f);
  for (int i = 0; i < cell_count; i++) { playTone(1976, 150); delay(100); }

  // Calibrate
  long sum_U = 0, sum_V = 0, sum_W = 0;
  for (int i = 0; i < 100; i++) { delay(2); sum_U += ADC1->JDR1; sum_V += ADC1->JDR2; sum_W += ADC2->JDR1; }
  offset_U = (int)(sum_U / 100); offset_V = (int)(sum_V / 100); offset_W = (int)(sum_W / 100);
}

// ==========================================
// 8. MAIN LOOP
// ==========================================
void loop() {
  uint32_t now_cycles = DWT->CYCCNT;
  static uint32_t last_cycles = 0;
  float dt = (float)(now_cycles - last_cycles) * (1.0f / 170000000.0f);
  if (dt <= 0.0f || dt > 0.01f) dt = 1e-4f;
  last_cycles = now_cycles;

  readELRS();

  // -------------------------------------------------------
  // STATE 0: IDLE / SAFE COASTING
  // -------------------------------------------------------
  if (!is_armed || elrs_throttle == 0.0f) {
      TIM1->CCER = 0xAAA; // Disconnect FETs
      motor_state = IDLE;
      current_velocity = 0.0f;
      V_alpha_cmd = 0.0f;
      V_beta_cmd = 0.0f;
      return; 
  } else {
      TIM1->CCER = 0xFFF; // Engage FETs
  }

  // -------------------------------------------------------
  // STEP 1: READ CURRENTS
  // -------------------------------------------------------
  float I_U = (float)((int32_t)ADC1->JDR1 - offset_U) * 0.008056f;
  float I_V = (float)((int32_t)ADC1->JDR2 - offset_V) * 0.008056f;
  float I_alpha = I_U;
  float I_beta  = (I_U + 2.0f * I_V) * 0.57735f;  

  // -------------------------------------------------------
  // STEP 2: BEMF OBSERVER (Runs continuously in background)
  // -------------------------------------------------------
  static float I_alpha_prev = 0.0f, I_beta_prev = 0.0f;
  float dIa_dt = (I_alpha - I_alpha_prev) / dt;
  float dIb_dt = (I_beta  - I_beta_prev)  / dt;
  I_alpha_prev = I_alpha; I_beta_prev  = I_beta;

  // BUG FIX: Feed observer the ACTUAL voltage commanded last cycle
  float E_alpha_raw = V_alpha_cmd - (R_phase * I_alpha) - (L_phase * dIa_dt);
  float E_beta_raw  = V_beta_cmd  - (R_phase * I_beta)  - (L_phase * dIb_dt);

  float lpf = dt / (0.002f + dt); // Slightly heavier filter for cleaner signal
  E_alpha = (1.0f - lpf) * E_alpha + lpf * E_alpha_raw;
  E_beta  = (1.0f - lpf) * E_beta  + lpf * E_beta_raw;

  float pure_bemf_angle = atan2f(-E_alpha, E_beta);
  float delta = pure_bemf_angle - last_pure_angle;
  while (delta >  _PI) delta -= _2PI;
  while (delta < -_PI) delta += _2PI;
  last_pure_angle = pure_bemf_angle;
  
  float obs_velocity = delta / dt;
  obs_angle = pure_bemf_angle;

  // -------------------------------------------------------
  // STEP 3: THE STARTUP STATE MACHINE
  // -------------------------------------------------------
  float Vd = 0.0f; 
  float Vq = 0.0f;

  if (motor_state == IDLE) {
      motor_state = ALIGN;
      state_timer = millis();
      electrical_angle = 0.0f;
  } 
  else if (motor_state == ALIGN) {
      // Park the rotor at 0 degrees
      Vd = 1.5f; // Small magnetic flux to hold it
      Vq = 0.0f;
      electrical_angle = 0.0f;
      
      if (millis() - state_timer > 300) { // Hold for 300ms
          motor_state = RAMP;
      }
  }
  else if (motor_state == RAMP) {
      // Blindly spin it up
      Vd = 0.0f;
      Vq = 1.5f; // Fixed, safe torque (prevents 27A spikes)
      current_velocity += 1500.0f * dt; // Accelerate smoothly
      electrical_angle += current_velocity * dt;

      // Handover Condition: Fast enough, and BEMF signal is loud enough
      if (current_velocity > 150.0f && (fabsf(E_alpha) > 0.5f || fabsf(E_beta) > 0.5f)) {
          motor_state = CLOSED_LOOP;
          current_velocity = obs_velocity; // Sync speed
      }
  }
  else if (motor_state == CLOSED_LOOP) {
      // WE ARE FLYING!
      Vq = 1.5f + (elrs_throttle * (POWER_SUPPLY - 1.5f)); 
      
      // Safety clamp: if speed drops to zero under load, trigger restart
      if (fabsf(obs_velocity) < 50.0f) {
          motor_state = ALIGN;
          state_timer = millis();
      }

      current_velocity = (0.95f * current_velocity) + (0.05f * obs_velocity);
      electrical_angle = obs_angle; // Snap to magnetic reality
  }

  // -------------------------------------------------------
  // STEP 4: SPACE VECTOR PWM (SVPWM) MODULATOR
  // -------------------------------------------------------
  float sin_e, cos_e;
  get_Fast_Sin_Cos(electrical_angle, &sin_e, &cos_e);

  V_alpha_cmd = Vd * cos_e - Vq * sin_e; // Save for next loop's observer
  V_beta_cmd  = Vd * sin_e + Vq * cos_e;

  float Va_raw = V_alpha_cmd;
  float Vb_raw = -0.5f * V_alpha_cmd + 0.866025f * V_beta_cmd;
  float Vc_raw = -0.5f * V_alpha_cmd - 0.866025f * V_beta_cmd;

  float v_min = fminf(Va_raw, fminf(Vb_raw, Vc_raw));
  float v_max = fmaxf(Va_raw, fmaxf(Vb_raw, Vc_raw));
  float v_com = -(v_max + v_min) * 0.5f;

  float Va_svpwm = Va_raw + v_com;
  float Vb_svpwm = Vb_raw + v_com;
  float Vc_svpwm = Vc_raw + v_com;

  TIM1->CCR1 = (uint16_t)(constrain((Va_svpwm / POWER_SUPPLY) + 0.5f, 0.05f, 0.95f) * 4250.0f);
  TIM1->CCR2 = (uint16_t)(constrain((Vb_svpwm / POWER_SUPPLY) + 0.5f, 0.05f, 0.95f) * 4250.0f);
  TIM1->CCR3 = (uint16_t)(constrain((Vc_svpwm / POWER_SUPPLY) + 0.5f, 0.05f, 0.95f) * 4250.0f);

  // -------------------------------------------------------
  // STEP 5: TELEMETRY (10 Hz)
  // -------------------------------------------------------
  static uint32_t last_print_ms = 0;
  if (millis() - last_print_ms > 100) {
    last_print_ms = millis();
    Serial.print("St:");   Serial.print(motor_state);
    Serial.print(",Thr:"); Serial.print(elrs_throttle * 100.0f, 0);
    Serial.print(",Spd:"); Serial.print(current_velocity, 0);
    Serial.print(",I_u:"); Serial.print(I_U, 2);
    Serial.print(",E_a:"); Serial.print(E_alpha, 2);
    Serial.println();
  }
}

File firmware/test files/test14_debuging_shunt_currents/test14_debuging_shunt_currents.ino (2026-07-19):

// =================================================================
// BARE-METAL AUTO-SPOOL CURRENT PLOTTER 
// Hardware-Triggered Injected Scan (G431 Edition)
// =================================================================
#include <Arduino.h>
#include <math.h>

#define _2PI 6.28318530718f
#define DRIVER_OFF HIGH

// --- STATE & CONTROL VARIABLES ---
float electrical_angle = 0.0;
float target_speed = 100.0f; // rad/s (Smooth, slow spin)
float amplitude = 0.0f;     // Starts at 0, ramps up safely

// --- ADC OFFSETS & FILTERS ---
int offset_U = 2048;
int offset_V = 2048;
int offset_W = 2048;

float filter_alpha = 0.05f; 
float filtered_U = 0.0, filtered_V = 0.0, filtered_W = 0.0;

// ==========================================
// 1. HARDWARE LOCKDOWN
// ==========================================
void hardware_lockdown() {
  pinMode(PA8,  OUTPUT); pinMode(PA9,  OUTPUT); pinMode(PA10, OUTPUT);
  pinMode(PB13, OUTPUT); pinMode(PB14, OUTPUT); pinMode(PB15, OUTPUT);
  digitalWrite(PA8, DRIVER_OFF);  digitalWrite(PB13, DRIVER_OFF); 
  digitalWrite(PA9, DRIVER_OFF);  digitalWrite(PB14, DRIVER_OFF); 
  digitalWrite(PA10, DRIVER_OFF); digitalWrite(PB15, DRIVER_OFF); 
}

// ==========================================
// 2. ADVANCED TIMER 1 (INVERTER PWM)
// ==========================================
void configureTIM1() {
  RCC->APB2ENR |= RCC_APB2ENR_TIM1EN;
  GPIOA->MODER = (GPIOA->MODER & ~0x3F0000) | 0x2A0000; 
  GPIOA->AFR[1] = (GPIOA->AFR[1] & ~0xFFF) | 0x666;
  GPIOB->MODER = (GPIOB->MODER & ~0xFC000000) | 0xA8000000; 
  GPIOB->AFR[1] = (GPIOB->AFR[1] & ~0xFFF00000) | 0x46600000; 
  
  TIM1->CR1 = 0x20; TIM1->PSC = 0; TIM1->ARR = 4250;
  TIM1->CCMR1 = 0x6868; TIM1->CCMR2 = 0x68;
  TIM1->CCER = 0xFFF;   
  TIM1->BDTR = 0x80A0;  
  
  TIM1->CR2 = 0xF3F; 
  // --- SYNC UPGRADE: Force TIM1 to generate a TRGO pulse on Update Event ---
  TIM1->CR2 &= ~TIM_CR2_MMS_Msk;             // Clear Master Mode bits
  TIM1->CR2 |= (0x2 << TIM_CR2_MMS_Pos);     // 010: Update Event = TRGO
  
  TIM1->EGR |= 1; TIM1->CR1 |= 1; 
}

// ==========================================
// 3. BARE-METAL ADCs (INJECTED HARDWARE SCAN)
// ==========================================
void setup_bare_metal_ADCs() {
  RCC->AHB2ENR |= RCC_AHB2ENR_GPIOAEN | RCC_AHB2ENR_GPIOBEN;
  GPIOA->MODER |= (3 << 2) | (3 << 8) | (3 << 12) | (3 << 14); 
  GPIOB->MODER |= (3 << 0);             
  
  RCC->AHB2ENR |= RCC_AHB2ENR_DAC1EN;       
  DAC1->CR |= 1; DAC1->DHR12R1 = 2048;                     

  RCC->AHB2ENR |= RCC_AHB2ENR_ADC12EN;
  ADC12_COMMON->CCR &= ~(3 << 16); ADC12_COMMON->CCR |= (1 << 16);
  
  ADC1->CR &= ~ADC_CR_DEEPPWD; ADC2->CR &= ~ADC_CR_DEEPPWD; delay(1);
  ADC1->CR |= ADC_CR_ADVREGEN; ADC2->CR |= ADC_CR_ADVREGEN; delay(1);
  ADC1->CR &= ~ADC_CR_ADCALDIF; ADC1->CR |= ADC_CR_ADCAL; while(ADC1->CR & ADC_CR_ADCAL);
  ADC2->CR &= ~ADC_CR_ADCALDIF; ADC2->CR |= ADC_CR_ADCAL; while(ADC2->CR & ADC_CR_ADCAL); delay(1);
  ADC1->ISR |= ADC_ISR_ADRDY; ADC1->CR |= ADC_CR_ADEN; while(!(ADC1->ISR & ADC_ISR_ADRDY));
  ADC2->ISR |= ADC_ISR_ADRDY; ADC2->CR |= ADC_CR_ADEN; while(!(ADC2->ISR & ADC_ISR_ADRDY));
  
  // Clean Sample Times
  ADC1->SMPR1 |= (3 << 6); ADC1->SMPR2 |= (3 << 15); ADC2->SMPR1 |= (3 << 12);

  // --- INJECTED SEQUENCE SETUP ---
  // ADC1 JSQR: Length=2 (U then V), Trigger=Rising Edge, Source=TIM1_TRGO (0)
  // Channel 15 (PB0) -> JDR1
  // Channel 2 (PA1)  -> JDR2
  ADC1->JSQR = (1 << 0) | (1 << 7) | (15 << 9) | (2 << 15);
  
  // ADC2 JSQR: Length=1 (W), Trigger=Rising Edge, Source=TIM1_TRGO (0)
  // Channel 4 (PA7)  -> JDR1
  ADC2->JSQR = (0 << 0) | (1 << 7) | (4 << 9);


  // ==================================================
  // THE MISSING BITS: ARM THE HARDWARE TRIGGERS!
  // ==================================================
  ADC1->CR |= ADC_CR_JADSTART;
  ADC2->CR |= ADC_CR_JADSTART;
}

// ==========================================
// MAIN SETUP
// ==========================================
void setup() {
  hardware_lockdown();
  Serial.begin(115200);
  delay(3000); 

  CoreDebug->DEMCR |= CoreDebug_DEMCR_TRCENA_Msk; 
  DWT->CYCCNT = 0; DWT->CTRL |= DWT_CTRL_CYCCNTENA_Msk;

  setup_bare_metal_ADCs();
  
  // --- CRITICAL REORDER ---
  // We MUST configure TIM1 before calibration. Since the ADCs are now strictly 
  // hardware-triggered, they won't collect data unless TIM1 is beating!
  configureTIM1(); 
  
  long sum_U = 0, sum_V = 0, sum_W = 0;
  for(int i = 0; i < 100; i++) {
      delay(2); // Wait 2ms (allows ~40 hardware triggers to happen in the background)
      sum_U += ADC1->JDR1; // U (PB0)
      sum_V += ADC1->JDR2; // V (PA1)
      sum_W += ADC2->JDR1; // W (PA7)
  }
  offset_U = sum_U / 100;
  offset_V = sum_V / 100;
  offset_W = sum_W / 100;

  Serial.print("RAW OFFSETS -> U: "); Serial.print(offset_U);
  Serial.print(" | V: "); Serial.print(offset_V);
  Serial.print(" | W: "); Serial.println(offset_W);

  Serial.println("System Ready. Auto-Spooling Motor with Injected Scan...");
}

// ==========================================
// MAIN LOOP
// ==========================================
void loop1() {
  uint32_t start_cycles = DWT->CYCCNT; 
  
  // 1. EXACT TIMING MATH
  static uint32_t last_cycles = 0;
  float dt = (float)(start_cycles - last_cycles) * 0.00000000588235f; 
  if(dt <= 0.0f || dt > 0.01f) dt = 1e-4f;
  last_cycles = start_cycles;

  // 2. AUTO RAMP-UP
  if (amplitude < 0.10f) {
      amplitude += 0.033f * dt; 
  }

  // 3. GENERATE SMOOTH SINE WAVES
  electrical_angle += target_speed * dt;
  while (electrical_angle >= _2PI) electrical_angle -= _2PI;
  while (electrical_angle < 0.0f) electrical_angle += _2PI;

  float duty_U = (sinf(electrical_angle) * amplitude) + 0.5f;
  float duty_V = (sinf(electrical_angle - 2.0944f) * amplitude) + 0.5f;
  float duty_W = (sinf(electrical_angle + 2.0944f) * amplitude) + 0.5f;

  TIM1->CCR1 = (uint16_t)(duty_U * 4250);
  TIM1->CCR2 = (uint16_t)(duty_V * 4250);
  TIM1->CCR3 = (uint16_t)(duty_W * 4250);

  // 4. GRAB INSTANT BACKGROUND HARDWARE DATA
  int raw_U = ADC1->JDR1; // PB0
  int raw_V = ADC1->JDR2; // PA1
  int raw_W = ADC2->JDR1; // PA7 (The suspect)

  // 5. PRINT RAW 12-BIT SILICON DATA TO PLOTTER
  static unsigned long last_plot_time = 0;
  if (millis() - last_plot_time > 20) { 
    Serial.print("Raw_U:"); Serial.print(raw_U); Serial.print(",");
    Serial.print("Raw_V:"); Serial.print(raw_V); Serial.print(",");
    Serial.print("Raw_W:"); Serial.println(raw_W);
    last_plot_time = millis();
  }
}
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
